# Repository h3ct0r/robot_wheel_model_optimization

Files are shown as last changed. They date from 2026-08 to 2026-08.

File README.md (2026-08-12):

# robot_wheel_model_optimization

Automatic optimisation of the 3D layout of wheels — **rigid (PLA/PETG) and compliant
(TPU), both candidates** — for a real, measured mobile robot: a 426 × 231 × 187 mm, 8.5 kg
four-wheel skid-steer pipe robot on Dynamixel MX-64 servos, carrying 20.6 N per wheel
(`configs/pipebot_detailed.stl`; `configs/robot.yaml` is the spec).

A parametric CAD model generates candidate wheels. Each is characterised by offline FEA,
reduced to a fast lumped-parameter ring model, and evaluated in closed-loop dynamic
simulation across an obstacle-traversal scenario suite. A multi-objective optimiser proposes
the next candidates. Designs are constrained to be FDM-printable, and the pipeline closes to
hardware.

**New here?** Read [`docs/OVERVIEW.md`](docs/OVERVIEW.md) — the project in plain language,
with a glossary of every acronym. No prior knowledge assumed.

**Status:** Phase 0 **closed** (2026-08-11); Phase 1's FEA→ROM pipeline is substantially
built. Current family is the `T7` compliant claw. The headline that matters now is the
**washboard**: a compliant twelve-claw wheel beats the rigid cylinder **4.8–6.9×** on ride
harshness at every wavelength tested, at equal speed. (The spike's old "50 mm vs 20 mm" step
number was superseded twice — it was a banded design on a single-wheel rig.) On the
measured platform the rover's step ladder separates compliant from rigid (claws 1.00 R
against the cylinder's 0.67 R) but not claw counts from each other; within the family,
harshness ranks — see `docs/plan/TODO.md` #30/#33. The ROM's
validity envelope is measured and printed on every run. Open items are numbered in
[`docs/plan/TODO.md`](docs/plan/TODO.md).

## Quick start

```bash
source /opt/homebrew/Caskroom/miniforge/base/etc/profile.d/conda.sh
conda activate conda3.12
python -m unittest discover -s tests -t .          # ~850 tests, ~50 s
python scripts/explore.py --spokes 8 --no-sim      # a design → one HTML page
```

Full setup, and why the first line is needed, is in [Environment](#environment) below.

## Where things are

| Path | Contents |
|---|---|
| [`docs/OVERVIEW.md`](docs/OVERVIEW.md) | **Start here** — plain-language summary and glossary |
| [`docs/run_rover.md`](docs/run_rover.md) | Every `run_rover.py` flag, with figures — the whole robot at an obstacle |
| [`CLAUDE.md`](CLAUDE.md) | Working context — current phase, invariants, conventions |
| [`docs/plan/`](docs/plan/00-index.md) | The project plan, split into loadable sections |
| [`docs/decisions/`](docs/decisions/README.md) | Architecture decision records |
| [`docs/experiments/log.md`](docs/experiments/log.md) | Append-only experiment log |
| [`configs/robot.yaml`](configs/robot.yaml) | The platform spec — sized to the real chassis, not yet frozen |
| [`docs/plan/TODO.md`](docs/plan/TODO.md) | **Open work, numbered** — read before picking something up |
| `src/wheelopt/cad/` | Parametric geometry → STEP + STL + mass properties |
| `src/wheelopt/fea/` | CalculiX driver: STEP → mesh → load cases → stiffness curve |
| `src/wheelopt/rom/` | The segmented ring and its fit. Pure numpy except `mjcf.py` |
| `src/wheelopt/sim/` | MuJoCo scenario runners — the step-climb rig and its signatures |
| `src/wheelopt/report.py` | The self-contained HTML report behind `scripts/explore.py` |
| `scripts/` | Entry points. `explore.py` is the manual playground; `verify_*.py` are the gates |

## The scenario suite

Every design is scored over these scenarios (`docs/plan/08-metrics.md`), each a real
`run_rover.py` run. The frames below are rendered from the simulation itself by
`scripts/render_scenario_gallery.py` — rigid R 60 wheels, the measured platform, the
robot's own shell — so they regenerate with the models they depict.

<table>
<tr>
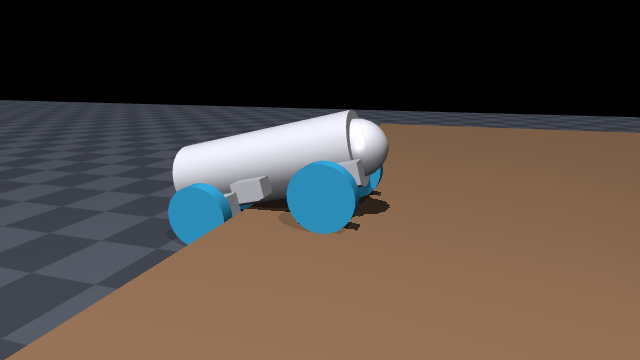
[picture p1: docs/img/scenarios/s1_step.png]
S1 step
<td width="50%"><br/>
<b>S1 — Step.</b> The obstacle ladder, 10–200 mm, swept over friction and approach-angle
seeds. Metric: the step height cleared with P = 0.9. Rigid R 60 clears 0.67 R; the claw
family 1.00 R.</td>
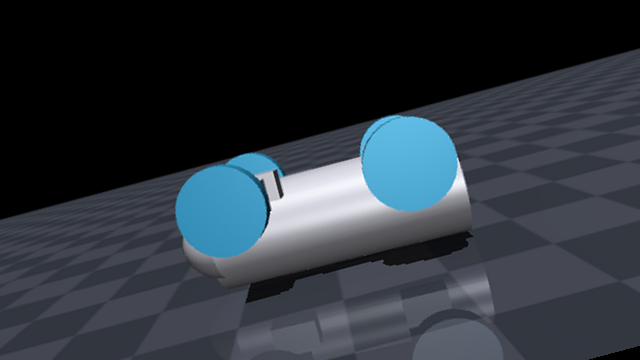
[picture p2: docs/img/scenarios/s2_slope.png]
S2 slope
<td width="50%"><br/>
<b>S2 — Slope.</b> An uphill gradient, implemented by tilting <i>gravity</i> so there is no
ramp-entry transient (the image is rotated by the same angle). Metric: max sustained
gradient. Rigid R 60 holds 10°, backslides at 40° — traction-limited.</td>
</tr>
<tr>
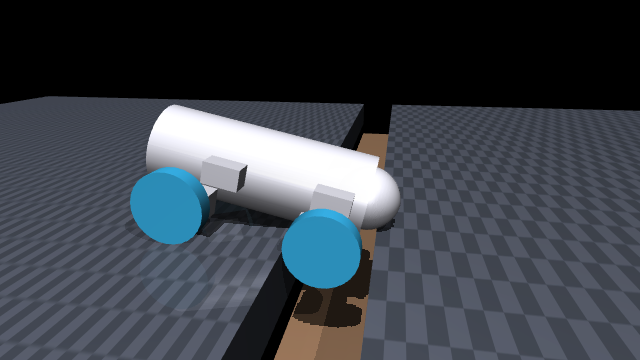
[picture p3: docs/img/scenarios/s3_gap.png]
S3 gap
<td><br/>
<b>S3 — Gap.</b> A 150 mm-deep trench across the ground; a wheel that drops in stays in
(pictured). Metric: max gap crossed with the whole body at ride height on the far side.
R 60 crosses 40 mm and is swallowed by 200.</td>
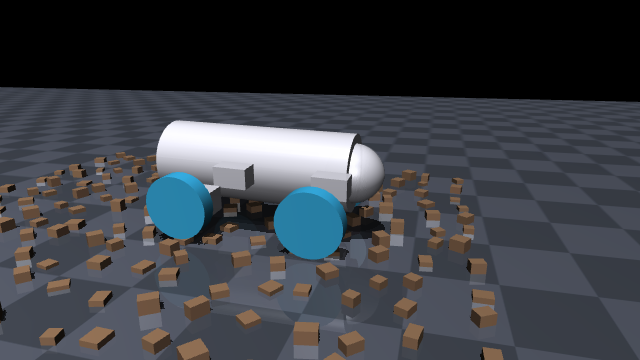
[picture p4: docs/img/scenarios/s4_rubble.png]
S4 rubble
<td><br/>
<b>S4 — Rubble.</b> A procedural rock field where the <i>seed is the terrain</i> —
bit-identical per seed, every rock buried and height-capped, by test. Metric: traverse
success and mean speed over seeds.</td>
</tr>
<tr>
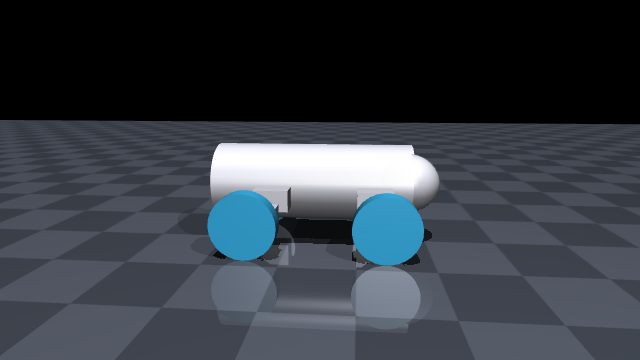
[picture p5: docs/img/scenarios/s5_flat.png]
S5 flat
<td><br/>
<b>S5 — Flat / cost of transport.</b> The anti-soft scenario: <code>E/(m·g·d)</code> on
flat ground, where a rigid cylinder is nearly free (0.01) and excess softness has to pay
for itself. Also the ride-harshness floor (objective 3).</td>
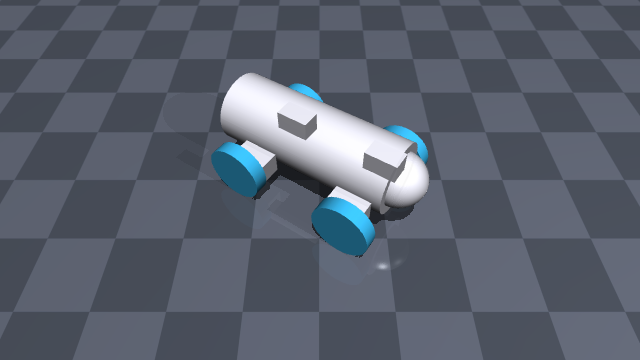
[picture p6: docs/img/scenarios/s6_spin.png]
S6 spin
<td><br/>
<b>S6 — Spin in place</b> (the path-track proxy). Left and right sides driven in
opposition; metric: yaw rate and the scrub energy it costs (6.8 °/s for 45.6 J on rigid
R 60). <i>Quarantined by TODO #38</i> until the lateral-scrub checks land.</td>
</tr>
<tr>
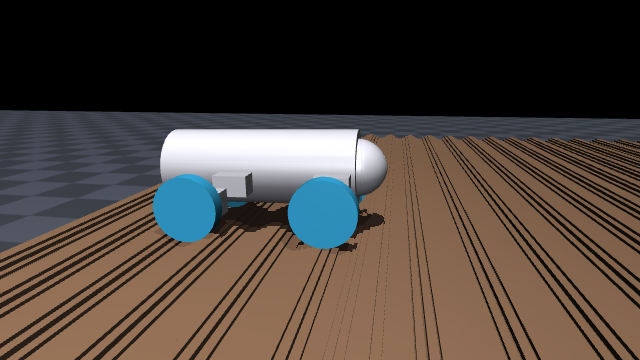
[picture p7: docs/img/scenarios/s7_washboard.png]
S7 washboard
<td><br/>
<b>S7 — Washboard.</b> A sinusoidal corrugation, swept over amplitude × wavelength.
Metric: RMS chassis acceleration — <b>where compliance wins</b>: the claw wheel beats the
rigid cylinder in every cell, 1.7–4.9×, and decouples from the terrain.</td>
<td><b>S8 — Sustained load</b> (no picture yet). Nominal + 2× load over long duration:
sag, buckling margin, fatigue. The anti-collapse scenario. Today it exists as FEA-side
constraints (<code>fea_static_sag</code>, <code>fea_buckling</code>); the duration and
fatigue half wants the TPU coupon data from <code>docs/plan/07-materials.md</code>.</td>
</tr>
</table>

## Environment

One conda environment, `conda3.12` (Python 3.12). Conda rather than a venv for two specific
reasons: **CalculiX has no PyPI distribution** (it is a Fortran binary, invoked as a
subprocess — [ADR-0005](docs/decisions/0005-calculix-for-batch-fea.md)), and **PyChrono has none either** — optional
since [ADR-0008](docs/decisions/0008-hardware-as-ground-truth.md) made printed hardware the ground truth. Everything else
installs from PyPI into the same environment.

### Activating it

```bash
source /opt/homebrew/Caskroom/miniforge/base/etc/profile.d/conda.sh
conda activate conda3.12
```

**The `source` line is not optional on this machine.** Running `conda activate conda3.12` on
its own fails with `Run 'conda init' before 'conda activate'`, because the conda-init block in
`~/.zshrc` is commented out *and* points at `/Users/h3ct0r/miniconda3`, a prefix that no longer
exists. (The `mamba` block just below it points at the same dead prefix, so the `mamba` alias
in that shell is also stale.) The working install is the homebrew miniforge one under
`/opt/homebrew/Caskroom/miniforge/base`.

To make plain `conda activate conda3.12` work permanently, initialise the shell against the
*live* prefix once — this edits `~/.zshrc`, so it is left as your call rather than done for you:

```bash
/opt/homebrew/Caskroom/miniforge/base/bin/conda init zsh
```

Then delete the two dead blocks in `~/.zshrc` that reference `miniconda3`, and open a new
shell.

**Do not use the system `python3`.** Homebrew's 3.14.6 ships a broken `pyexpat` that breaks
`pip` itself.

### Creating it from scratch

```bash
brew install --cask miniforge
conda create -y -n conda3.12 -c conda-forge python=3.12 calculix=2.23
conda activate conda3.12
pip install -e '.[cad,fea,sim,viz,store,dev]'
```

### Checking it

```bash
python -c "import sys; print(sys.executable)"   # .../envs/conda3.12/bin/python
ccx -v                                          # CalculiX Version 2.23
python -m unittest discover -s tests -t .       # 824 tests
```

`ccx -v` prints the version and then **exits 201**. That is normal — it is not an error, and
nothing in the pipeline reads that exit code.

### What needs what

The extras are separate on purpose: a screening-only worker installs none of them, and the
numpy-only layers stay testable on a machine with no CAD kernel and no simulator.

| Extra | Brings | Needed by |
|---|---|---|
| *(none)* | numpy only | screening, centreline geometry, mass properties, the ring maths and its fit |
| `cad` | build123d / OCCT | building solids, STEP and STL export |
| `fea` | gmsh | meshing. **The solver `ccx` is a conda binary, not a pip package** |
| `sim` | mujoco | the ring in dynamics, the step-climb rig, rendering |
| `viz` | matplotlib | `--plot-pdf` and the HTML report |
| `store` | duckdb + pyarrow | the experiment store and the determinism gate |

## Running it

Everything below assumes the environment is active. Times are on this machine; the FEA cache
is content-addressed, so a repeated design is near-instant.

### The playground — start here

One design (or several) through the whole chain into a single self-contained HTML page:
section drawing, load curve, tangent stiffness, contact patch, fitted segment law, step-climb
signatures and an embedded animation.

```bash
python scripts/explore.py --spokes 8 --thickness 6 --no-sim      # ~1 min cold, ~2 s cached
python scripts/explore.py --compare spokes=6,10,14 --no-sim      # shared axes
python scripts/explore.py --rim-thickness 0 --claw-taper 0.6 --spoke-phase -90
```

Output lands in `data/explore/explore.html`. Every panel is labelled with the tier that
produced it and whether that tier **screens or decides**; panels whose numbers are currently
untrustworthy carry a caution banner. Read the banner before quoting the number.

### Individual stages

```bash
# What every geometry parameter does, one figure per parameter, with the screening
# verdict under each design. Seconds, and needs no CAD kernel.
python scripts/plot_geometry.py --contact-sheet

# Screen a design without building geometry. Milliseconds, no OCCT.
python scripts/gen_wheel.py --screen-only --spokes 14 --thickness 6.0

# Build it: STEP + STL + mass properties.
python scripts/gen_wheel.py --radius 85 --spokes 12 --profile curved --out data/wheels

# FEA, mesh and deck only, no solver. The developer loop.
python scripts/run_fea.py --dry-run --tiny --case flat --case step_edge

# FEA on the fast 2-D screening tier. Seconds, not hours.
# (the softened contact penalty this tier once needed by hand is the default since #12)
python scripts/run_fea.py --plane-strain --size-spoke 0.0025 --size-rim 0.003 \
    --size-hub 0.002 --case flat --plot-pdf

# Fit the segmented ring to the FEA curve, and optionally press it in MuJoCo.
python scripts/run_rom.py --tiny --mujoco

# Drive the fitted ring at a step beside a rigid wheel; judge the five signatures.
python scripts/run_step.py --tiny --sweep

# The whole robot — chassis, four driven wheels, its own shell drawn over the
# contact box — at an obstacle, filmed. --chassis-collision primitives swaps the
# calibrated box for the shapes of the simplified model (a physics change).
python scripts/run_rover.py --obstacle-height 80 --radius 85 --render

# Scenario S7: a washboard, where compliance beats rigid on harshness.
python scripts/run_rover.py --obstacle-height 0 --washboard 10 --wavelength 100 --radius 60

# Render the step climb: GIF plus a compliant-vs-rigid contact sheet.
python scripts/render_step.py --tiny
```

`run_rover.py` has the largest flag surface of any entry point here — the obstacle, the
platform, a whole wheel design, the FEA behind it, and the render. Every flag is documented
with figures in **[`docs/run_rover.md`](docs/run_rover.md)**, including which flags are
silently unused in the default rigid-cylinder mode.

### Verification batteries

Run these after touching the layer they cover. They need the real kernels — the unit tests
deliberately cannot catch what these catch.

```bash
python scripts/verify_cad.py            # 48 checks against OCCT
python scripts/verify_fea.py --full     # 30 checks against CalculiX (tens of minutes uncached)
python -m unittest discover -s tests -t .
```

### A caveat worth reading once

The 2-D plane-strain tier is what makes the loop interactive, and it is a **deliberate
fidelity reduction, not an approximation that improves with refinement**. It cannot see
lateral spoke buckling at all. Measured against the 3-D solid at matched settings: force ratio
0.90, stiffness ratio 0.86, patch length 0.95. Use it to screen; let the 3-D tier decide.

## Approach in one paragraph

Full FEM of a compliant wheel inside an optimisation loop is 3–5 orders of magnitude too
slow; rigid-body simulation cannot represent contact-patch growth, load-dependent rolling
radius, or hysteretic loss at all. The approach borrows the automotive tire field's solution:
generate a reduced-order flexible-ring model from FEA, run that in a fast rigid-body engine,
and — after a few hundred FEA runs — surrogate the FEA step away entirely so that design
*search* becomes tractable. Validity is checked by cross-engine rank correlation against
Chrono ANCF FEA tires, and finally against printed hardware.

## Key decisions at a glance

- **MuJoCo** hosts the inner loop. Isaac soft bodies are unusable here — PhysX soft bodies
  don't support static friction. ([ADR-0001](docs/decisions/0001-mujoco-over-isaac-for-inner-loop.md))
- **Reduced-order ring model**, calibrated offline from FEA. FEM never runs in the loop.
  ([ADR-0002](docs/decisions/0002-reduced-order-model-over-fem.md))
- **build123d** for CAD, because FEA needs STEP and multi-material needs region tagging.
  ([ADR-0003](docs/decisions/0003-build123d-over-openscad.md))
- **Printed hardware** as ground truth; Chrono ANCF demoted to an optional cross-check.
  ([ADR-0008](docs/decisions/0008-hardware-as-ground-truth.md), superseding [ADR-0004](docs/decisions/0004-chrono-as-ground-truth.md)'s gating role)
- **Pareto search on CVaR**, no scalarisation, measured termination.
  ([ADR-0006](docs/decisions/0006-multi-objective-not-scalarised.md))

## Licence

TBD.

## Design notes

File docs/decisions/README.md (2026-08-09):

# Architecture decision records

One file per non-obvious decision. **Read the relevant ADR before proposing a change to
simulator choice, modelling fidelity, or the CAD toolchain** — several plausible-sounding
alternatives were evaluated and rejected for specific documented reasons.

| ADR | Decision | Status |
|---|---|---|
| [0001](0001-mujoco-over-isaac-for-inner-loop.md) | MuJoCo hosts the inner loop; Isaac soft bodies rejected (no static friction) | accepted |
| [0002](0002-reduced-order-model-over-fem.md) | Reduced-order ring model calibrated from FEA; **FEM never in the loop** | accepted |
| [0003](0003-build123d-over-openscad.md) | build123d for CAD; STEP required for FEA and material region tagging | accepted |
| [0004](0004-chrono-as-ground-truth.md) | Chrono ANCF as computational ground truth; never in the loop | accepted |
| [0005](0005-calculix-for-batch-fea.md) | CalculiX for batch quasi-static FEA; FEniCSx as escape hatch | accepted |
| [0006](0006-multi-objective-not-scalarised.md) | Pareto search on CVaR; no scalarisation; measured termination | accepted |
| [0007](0007-coacd-for-convex-decomposition.md) | CoACD over V-HACD for collision geometry | accepted |

## Conventions

- Number sequentially. Never renumber.
- **Supersede, don't delete.** When a decision changes, write a new ADR that supersedes the
  old one and mark the old one `superseded by ADR-NNNN`. The reasoning that turned out wrong
  is as valuable as the reasoning that turned out right.
- Keep them short — roughly one page. Context, decision, alternatives *with specific reasons*,
  consequences, revisit-if.
- The **"Revisit if"** section is the most valuable part. It states the observable condition
  that would justify reopening the question, which prevents both premature churn and stubborn
  adherence.
- Use [`0000-template.md`](0000-template.md) as the starting point.

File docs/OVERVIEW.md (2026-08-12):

# Overview — the project in plain language

A one-sitting orientation. No prior knowledge assumed. Every acronym is spelled out the
first time and collected in the [glossary](#glossary) at the end.

The detailed plan lives in [`docs/plan/`](plan/00-index.md); this file is the map, not the
territory.

---

## 1. What we are building, in one paragraph

We are designing **3D-printed wheels — both stiff plastic and squishy TPU, the optimiser
picks** — for a real four-wheeled pipe-inspection robot about the size of a large toolbox:
426 × 231 × 187 mm, 8.5 kg, on four Dynamixel servos, measured off its own 3D model
(`configs/pipebot_detailed.stl`). Each wheel carries about 20.6 N, bolts to the servo's
53 mm horn, and comes out 80–180 mm across.
Instead of guessing a good wheel shape, we let a computer try thousands of shapes, simulate each one driving at obstacles, and pick
the best. The hard part is not the searching. The hard part is **simulating squishiness fast
enough to search at all**. Most of this project is the machinery that makes that possible.

## 2. The problem, and why it is hard

**Rigid wheels are easy to simulate and bad at obstacles.** A hard plastic wheel touches the
ground at essentially one point. Hitting a step, it either has enough torque and radius to
climb, or it stalls.

**Squishy wheels are good at obstacles and hard to simulate.** A soft wheel *wraps around* a
step edge. That does three useful things at once:

1. it grips more, because more rubber is touching the obstacle,
2. it effectively grabs the corner instead of pushing against it,
3. it absorbs shock, so the robot is not shaken apart.

The catch: soft wheels are also slower and less efficient on flat ground, because squishing
and un-squishing wastes energy. **So there is a real trade-off to optimise** — that is the
research question, not a foregone conclusion.

**Why simulating squishiness is hard.** Properly simulating a deforming rubber structure
means finite element analysis (FEA) — chopping the wheel into ~50,000 little chunks and
solving how each one pushes on its neighbours. That takes **minutes per wheel position**. To
optimise, we need to simulate a robot *driving* — thousands of positions per run, thousands
of runs. Doing it directly would be roughly **1,000 to 100,000 times too slow**.

> The naive fix — telling the physics engine "make the contact a bit soft" — does not work.
> That is a numerical smoothing knob, not a model of rubber. It cannot reproduce the contact
> patch growing under load, the wheel wrapping a corner, or energy loss. Mistaking one for
> the other is the single easiest way to get a confident, wrong answer, so the project bans
> it outright (see [invariant 8](#7-the-rules-we-do-not-break)).

## 3. The core idea

Borrowed from the car-tyre industry, which solved this decades ago:

> **Measure the squishiness carefully once. Boil it down to a handful of numbers. Then
> simulate a cheap fake wheel that behaves the same way.**

Concretely, we replace the soft wheel with a **ring of 24–48 rigid blocks connected by
springs**. It is not made of rubber, and it does not deform like rubber internally — but
under load it *pushes back* like the real wheel does, because we tuned the springs to match
the slow accurate simulation. That fake wheel runs fast enough to drive around.

The technical name for "cheap stand-in tuned to match an expensive model" is a
**reduced-order model (ROM)**. It is the heart of the project.

```mermaid
flowchart LR
    A["<b>1. CAD</b><br/>describe a wheel<br/>with ~10 numbers"]
    B["<b>2. FEA</b><br/>squash it slowly<br/>and accurately<br/><i>minutes</i>"]
    C["<b>3. ROM</b><br/>fit a spring-ring<br/>to match<br/><i>seconds</i>"]
    D["<b>4. SIM</b><br/>drive at obstacles<br/>thousands of times<br/><i>milliseconds</i>"]
    E["<b>5. OPTIMISER</b><br/>propose better<br/>wheels"]
    A --> B --> C --> D --> E
    E -.->|next candidate| A
```

**The key structural rule: step 2 never runs inside the loop.** FEA happens once per design,
offline, and the result is cached. The loop only ever runs the cheap version. Later, we skip
even that — after a few hundred designs we train a predictor that guesses the spring values
straight from the shape, so most designs skip FEA entirely.

## 4. The pipeline, stage by stage

| # | Stage | Input | Output | Software | Speed |
|---|---|---|---|---|---|
| 1 | **CAD** — build the shape | ~10 numbers (radius, spoke count, thickness…) | 3-D solid + weight | **build123d** — the Python library we write shapes in. **OCCT** (via **OCP**) — the geometry kernel underneath it, which does the actual solid modelling and writes the STEP file. **NumPy** — spoke maths, screening and weight, all of which run *without* the kernel. **matplotlib** — optional, draws the PDF report | seconds |
| 2 | **FEA** — measure stiffness | the 3-D solid, or a slice through it | how hard it pushes back | **gmsh** — chops the wheel into ~50,000 tetrahedra, or the flat cross-section into ~2,600 triangles. **CalculiX** (`ccx` 2.23) — the solver; a standalone program we launch and exchange text files with, not a Python library. **NumPy** — reads the solver's output back and extracts the curve | ~20 s for a slice, ~20 h for the full solid |
| 3 | **ROM** — fit the stand-in | the stiffness curve | spring settings | **NumPy** / **SciPy** — the curve fitting itself. **MuJoCo** — the ring model is built and exercised here to check the fit is real. Later, **BoTorch** / **GPyTorch** — a predictor that guesses spring settings straight from the shape, skipping FEA entirely | seconds |
| 4 | **SIM** — drive it | the spring-ring wheel | did it climb? how fast? how much energy? | **MuJoCo** — the fast physics engine that runs the scenarios. **CoACD** + **trimesh** — cut the shape into simple convex pieces the engine can collide quickly. **PyChrono** — a slower, much more accurate independent simulator, used only to check the cheap model, never inside the loop | milliseconds |
| 5 | **OPTIMISER** — choose next | all scores so far | the next shapes to try | **Ax** / **BoTorch** — the Bayesian optimiser. **CMA-ES** or **NSGA-II** — final local polish, which evolution strategies do better than Bayesian methods. **Hydra** — configuration, so no number is buried in code. **DuckDB** + **Parquet** — stores every run, one row per design × scenario × seed | seconds |

Installed and running today: everything in stages 1 and 2, plus NumPy throughout. The rest is
the intended stack, chosen in the decision records (§8) but not yet built — see the road map
in §6. All of it is free and open-source, and all of it runs on one laptop.

Two practical notes. **CalculiX and PyChrono are not normal Python packages**: `ccx` is a
compiled program that we run as a separate process, and PyChrono has no PyPI release at all.
That is the entire reason the project uses a conda environment rather than a plain
`virtualenv`. And **the heavy pieces are optional** — a machine that only screens designs for
printability needs NumPy and nothing else, which is why the install is split into
`[cad]`, `[fea]` and `[viz]` extras.

### Stage 1 — CAD (Computer-Aided Design)

A program writes the wheel, rather than a human drawing it. Give it a handful of numbers —
outer radius, width, number of spokes, spoke thickness, how curved the spokes are — and it
produces a real 3-D solid.

It also **screens the design first**, in milliseconds: are the spokes so close together the
printer nozzle cannot fit between them? Is it too big for the robot? A bad design is rejected
before any expensive work happens.

*Status: done and verified.*

### Stage 2 — FEA (Finite Element Analysis)

Take the solid, chop it into ~50,000 tetrahedra, and press it against an obstacle in small
steps, solving the whole structure each time. We do this twice:

- **against a flat plate** — the reference measurement,
- **against a step edge** — the case that actually decides obstacle climbing, and the one the
  published tyre literature tends to skip.

Out comes the **stiffness curve** `k_r(δ)`: how much force it takes to squash the wheel by a
given amount. Plus the contact patch size, how much the wheel's effective radius shrinks
under load, and whether the spokes buckle.

*Status: done and verified — 20/20 checks pass.*

### Stage 3 — ROM (Reduced-Order Model)

Fit the ring-of-blocks-and-springs so its force-versus-squash curve matches what FEA
measured. Then check honestly how close the match is, and report the error.

*Status: next up.*

### Stage 4 — SIM (dynamic simulation)

Drive the robot at obstacles in MuJoCo, a fast physics engine. Eight scenarios (S1–S8):
steps, slopes, gaps, rubble, a flat sprint, path following, washboard ripples, sustained
load. Each design is scored on obstacle capability, energy use, speed and ride quality.

Every design is run many times over **different random terrains and different plausible
rubber properties**, because we do not precisely know the material — and a design that only
works for one exact rubber recipe is useless in practice.

*Status: not started.*

### Stage 5 — OPTIMISER

Propose the next batch of shapes to try, using Bayesian optimisation — a method that builds a
running guess of "which regions of the design space look promising" and samples there.

Crucially it keeps the objectives **separate** rather than mashing them into one score. There
is no single best wheel; there is a *set* of best trade-offs (a **Pareto front**) — this one
climbs better, that one is more efficient. Collapsing that into one number destroys the
actual result.

*Status: not started.*

## 5. Where the project is right now

**Phase 0 (foundations) closed 2026-08-11; Phase 1's FEA→ROM pipeline is substantially
built**, well ahead of the original [one-week spike](plan/16-first-week.md) whose steps the
table below tracks — all six answered yes. The ground truth is now printed hardware
(ADR-0008), and the next gate is a bench press test of a printed wheel.

| Step | What | Status |
|---|---|---|
| 1 | Freeze the robot specification | measured robot adopted 2026-08-11; frozen once CoM/inertia arrive |
| 2 | CAD: shape → 3-D solid | **done**, 60/60 checks |
| 3 | FEA: solid → stiffness curve | **done**, 30/30 checks, plus a fast 2-D screening tier |
| 4 | ROM: fit the spring-ring | **done** — and for claw wheels the law is *measured*, not fitted |
| 5 | Drive it at a step edge vs a rigid wheel | **done** — 5/5 signatures; the whole 4-wheel robot runs too |
| 6 | Look hard at the result, decide whether to continue | **yes** — compliance beats rigid on the washboard and on the rover's step ladder |

**What we already know works.** A test wheel (60 mm radius, 6 spokes, TPU) pressed into an
obstacle behaves correctly: it gets stiffer the more you squash it, its contact patch
grows, its effective radius shrinks, and — the important one — **against a step edge the
contact is smaller and the pressure higher than against a flat plate**. That is the
envelopment signature. It is the mechanism that lets a soft wheel climb, and it showed up in
the numbers without being put there.

**The big open question**, and the reason for the spike: does the cheap spring-ring model
actually reproduce the real behaviour well enough to optimise against? If not, the plan is to
fall back to a simpler wheel family (soft tread on a rigid hub) and narrow the claims. Better
to learn that in week 14 than week 30.

## 6. The road map

| Phase | Weeks | What happens | Gate to pass |
|---|---|---|---|
| **0 Foundations** | 1–4 | Robot spec, repo, rigid wheel rolling end-to-end | Same design → same score, two machines, two days apart |
| **1 FEA + ROM** | 5–14 | The critical path. Build and validate the stand-in model | ROM within 10% of FEA stiffness; ranking agreement ρ > 0.8 |
| **2 Optimiser** | 15–24 | Full scenario suite, ≥ 300 designs/day, train the shape → springs predictor | Beats random search, with confidence intervals |
| **3 Main campaign** | 25–36 | 2,500–3,500 designs across all wheel families; validity audits | Cross-engine agreement ρ > 0.7 |
| **4 Hardware** | 37–50 | Print 8 wheels, build a test rig, measure reality | Sim-to-real correlation reported honestly, whatever it is |
| **5 Write-up** | 51–60 | Release the benchmark; papers | — |

A **gate** is a go/no-go checkpoint. Failing one means stopping and rethinking, not pressing
on. Phase 1's gate is the one that matters most: *if the cheap model cannot reproduce the
expensive one, the whole approach needs rethinking.*

## 7. The rules we do not break

These are in [`CLAUDE.md`](../CLAUDE.md) as "invariants". In plain terms:

1. **Never run the slow, accurate simulation inside the search loop.** It is offline and
   cached, always.
2. **Always compute weight and stiffness from the actual shape and material.** Never hard-code
   them, never hold them fixed between designs. A wheel whose stiffness silently never changes
   would produce beautiful, meaningless results.
3. **Rejecting a bad design must be cheap** — milliseconds, not a six-minute simulation.
4. **Nothing crashes the campaign.** A failed simulation returns "this failed, here is why",
   never an error that stops everything. Running thousands of nonlinear simulations
   unattended, some *will* fail; that is normal, and it gets logged as a health metric.
5. **Change the method, invalidate the old results.** Every cached result is tagged with the
   version of the code that produced it, so nothing stale is ever silently reused.
6. **Keep the objectives separate.** No single blended score.
7. **Score every design across many random terrains and material guesses**, and judge it by
   its *bad* days, not its average day (a measure called CVaR). Robustness is a requirement,
   not a refinement.
8. **The physics engine's "soft contact" setting is not squishiness.** Never use it as a
   stand-in for rubber.

## 8. Key decisions, and why

Recorded as ADRs — Architecture Decision Records, one file per decision, in
[`docs/decisions/`](decisions/README.md). Each records what was chosen, what was rejected,
and *why*, so nobody re-litigates it from memory.

| # | Decision | Short reason |
|---|---|---|
| 0001 | MuJoCo for the fast inner loop | Fast and reliable. NVIDIA's soft-body engine was rejected because it has no static friction — meaning no correct grip, which breaks the whole point |
| 0002 | Stand-in model instead of real FEM in the loop | Real FEM is 1,000–100,000× too slow |
| 0003 | build123d for CAD, exporting STEP | FEA needs true curved surfaces, not a triangle mesh |
| 0004 | Chrono as "ground truth" | An independent, much more accurate simulator to check our cheap model against — never used in the loop |
| 0005 | CalculiX for the FEA | Free, scriptable, batch-friendly, boring in the good way |
| 0006 | Keep objectives separate (Pareto) | Blending them into one number destroys the actual finding |
| 0007 | CoACD for collision shapes | Better shape approximation than the older standard |

## 9. Two honest limitations

Stated up front, because they shape what the project can claim:

- **We do not have lab equipment to measure the rubber properly.** We use published values
  and cheap DIY tests. So we cannot make precise absolute predictions — we can rank designs.
  The project turns this into a research question: *how much does not knowing the material
  cost you, and can you optimise in a way that is robust to not knowing?*
- **Energy loss in the rubber is not modelled from first principles.** The material model we
  can afford is "springy but lossless", so the FEA cannot produce a hysteresis (energy-loss)
  number. That is a real gap, and it is written down rather than filled with a plausible
  guess.

## 10. Running things

Everything assumes the project environment is active: `conda activate conda3.12`.

```bash
# Fast checks — no heavy dependencies, about a second.
python -m unittest discover -s tests -t .

# Is this design even buildable? Milliseconds, no CAD kernel.
python scripts/gen_wheel.py --screen-only --spokes 20 --thickness 2.4

# Build a wheel: 3-D file + weight + a PDF drawing.
python scripts/gen_wheel.py --radius 70 --spokes 16 --plot-pdf

# FEA without the solver — builds the mesh and input file only.
python scripts/run_fea.py --dry-run --tiny --case flat --case step_edge

# The real thing: squash the wheel, plot the results.
python scripts/run_fea.py --tiny --case flat --case step_edge --plot-pdf

# Full verification batteries.
python scripts/verify_cad.py
python scripts/verify_fea.py --full
```

---

## Glossary

### The essentials

| Term | Meaning |
|---|---|
| **Compliant** | Squishy. Deforms usefully under load. The opposite of rigid |
| **TPU** | Thermoplastic Polyurethane — flexible 3-D printing filament. The rubber-like stuff |
| **FDM** | Fused Deposition Modelling — ordinary filament 3-D printing |
| **FEA / FEM** | Finite Element Analysis / Method — chop an object into small chunks and solve how it deforms. Accurate, slow |
| **ROM** | Reduced-Order Model — a cheap stand-in tuned to behave like an expensive model |
| **Contact patch** | The area actually touching the ground. Bigger = more grip |
| **Envelopment** | A soft wheel wrapping around an obstacle instead of bumping into it |
| **Buckling** | A slender part suddenly collapsing sideways instead of squashing evenly |
| **Hysteresis** | Energy lost as heat when a material is squashed and released |
| **Pareto front** | The set of best trade-offs, when no single design wins at everything |
| **CVaR** | Conditional Value at Risk — the average of the *worst* outcomes. Judging a design by its bad days |

### File formats and tools

| Term | Meaning |
|---|---|
| **CAD** | Computer-Aided Design |
| **STEP** | Exact 3-D format with true curved surfaces. Our source of truth |
| **STL** | Triangle-mesh 3-D format. Approximate, derived, never authoritative |
| **BREP** | Boundary Representation — how STEP describes shapes exactly |
| **OCCT / OCP** | Open CASCADE Technology — the geometry engine underneath build123d |
| **build123d** | The Python library we write CAD in |
| **gmsh** | Chops a solid into elements for FEA |
| **CalculiX (`ccx`)** | The FEA solver. A standalone program we call and read files from |
| **MuJoCo** | The fast physics engine for the inner loop |
| **Chrono / PyChrono** | A much slower, much more accurate simulator, used as a reference |
| **NumPy / SciPy** | The standard Python numerical libraries. Arrays, and curve fitting |
| **matplotlib** | Draws the PDF reports |
| **CoACD / trimesh** | Cut a shape into simple convex pieces so collisions are fast to compute |
| **Ax / BoTorch / GPyTorch** | Meta's Bayesian-optimisation stack. Ax runs the experiment, BoTorch and GPyTorch do the maths underneath |
| **CMA-ES / NSGA-II** | Evolutionary search methods. Better than Bayesian optimisation at the final polish, worse at the broad hunt |
| **Hydra** | Configuration system, so settings live in files rather than buried in code |
| **DuckDB / Parquet** | A database and a file format for storing results. Fast for "give me every run where…" questions |
| **conda / conda-forge** | Package manager and its community repository. Used here because two of our tools are not installable any other way |
| **ADR** | Architecture Decision Record |

### Things you will see in the code

| Term | Meaning |
|---|---|
| **`k_r(δ)`** | Radial stiffness — how much force to squash the wheel by distance δ. The main FEA output |
| **Load case** | One specific test: "press against a flat plate", "press against a step edge" |
| **Mooney-Rivlin** | A mathematical description of how rubber stiffens as you stretch it |
| **C3D10** | A curved 10-cornered tetrahedral element — the chunk shape our FEA uses |
| **DOF** | Degrees of Freedom — how many unknowns the solver handles. ~50,000 here |
| **Jacobian** | A measure of whether an element is a sane shape or folded inside-out |
| **`T0`…`T6`** | Wheel families: `T0` rigid cylinder (baseline), **`T3` compliant spoke (our main target)**, `T4` all-TPU, `T5` spokes + lugs, `T6` soft tread on rigid hub (fallback) |
| **`S1`…`S8`** | Test scenarios: step, slope, gap, rubble, flat sprint, path tracking, washboard, sustained load |
| **`RQ1`…`RQ4`** | The four research questions — design trade-offs, method, validity, robustness |
| **Invariant** | A rule that must never be broken, listed in `CLAUDE.md` |
| **Gate** | A go/no-go checkpoint at the end of a phase |
| **NPT** | Non-Pneumatic Tire — airless tyres. The closest existing literature |
| **Spearman ρ** | A 0–1 score for "do two rankings agree?" Used to check simulation against reality |

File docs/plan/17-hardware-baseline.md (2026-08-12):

# 17 — Freezing the platform, and the hardware ground-truth protocol

Two jobs in one file, because they share equipment and an afternoon: **(A)** measure the real
robot so `configs/robot.yaml` can set `meta.frozen: true`, and **(B)** the bench protocol
ADR-0008 promotes to ground truth. Everything downstream carries a "these are estimates"
caveat until (A) is done, and the ROM's multi-claw regime has no calibration path until (B).

## A. Freezing `robot.yaml` — every field, how to get it, what it replaces

**Status 2026-08-11: the measurements arrived, and they changed the robot.** Received: the
motor (4x Dynamixel MX-64AT at 12 V — 6.0 N·m stall, 63 rpm no-load, at the output), 8.5 kg
all-up, 3 cm clearance, and the 3D model (`configs/pipebot_detailed.stl`, at the time named `robot_piperobot.stl`). Mining the STL:
**wheelbase 250 mm, track 157 mm (not the assumed 350), overall 426 x 231 x 187, existing
wheels r ~22.5 mm** — a pipe robot with a circular ~187 mm shell, not the assumed
400x300x200 box. The model's own clearance (34 mm) cross-checks the hand measurement. The
searched wheel range (R 60-100) collides with the real machine; adoption of the measured
geometry is pending the open questions below.

**Open questions the STL cannot answer** (they gate the design-space re-derivation):
1. **Must the robot keep fitting a pipe, and what bore(s)?** The circular shell says
   pipe-fit; a larger wheel lifts the whole body and changes that fit. This sets the wheel
   radius ceiling, which no geometry measurement can.
2. **What rotates at r 26.5 mm from the axles** — servo horn (rotates, caps nothing) or a
   fixed bracket (caps the wheel at ~26 mm)? One photo of a wheel answers it.
3. **How much axial room is there for a wider wheel** outboard/inboard of the current one?
4. The 8.5 kg: with or without the current wheels and battery? (Now minor — the existing
   wheels are tiny — but it settles `nominal_wheel_load`.)

Ordered by leverage: the first three touch every number in the project.
**The table predates the 2026-08-11 arrival and is kept as the method reference** — its
"current" column shows the old estimates the measurements replaced. Still genuinely open:
`com_offset`, `inertia` (both want the 3D model with component masses assigned), and the
per-corner masses.

| Field | Current (estimate) | How to measure | Effort |
|---|---|---|---|
| `chassis.mass` | 8.8 kg | Bathroom/kitchen scale, robot ready-to-run **with battery, without wheels**. Weigh wheels separately | 5 min |
| `motor.stall_torque` (at output) | 4.0 N·m | Preferred: **datasheet** from the motor brand + gear ratio (see below). Cross-check: lever arm clamped to one axle pressing on a kitchen scale at a known radius, battery at working charge, brief stall — `τ = m·g·r`. Keep stalls under ~2 s | 30 min |
| `motor.no_load_speed` | 14.0 rad/s | Datasheet, cross-checked by video: tape flag on a wheel, phone slow-mo (240 fps), count frames per revolution at full throttle off the ground | 15 min |
| `chassis.com_offset` | (0, 0, 0) | Balance method: find the tip line by tilting the robot on a straightedge along each axis; or read it from the **3D model** if component masses (battery!) are placed. The z-offset moves both tip-over angles directly — objective 5 depends on it | 30 min |
| `chassis.inertia` | uniform-box formula | From the **3D model** with real component masses assigned (any CAD package reports it). The box formula over-estimates for a robot whose mass concentrates low and central — which flatters nothing but is wrong | via 3D model |
| `wheelbase`, `track` | 260 / 350 mm | Tape measure axle-to-axle, or the 3D model. Trust the model only if the built robot matches it | 5 min |
| `ground_clearance` | 70 mm | Measure under the chassis at ride height with current wheels | 2 min |
| `wheel_envelope.max_radius` | 100 mm (**derived from a dead printer**) | The chassis wheel well: from the 3D model, the largest radius that clears body, fasteners and neighbouring wheel at full articulation, minus 5 mm | via 3D model |
| `shaft` interface | 8 mm D-shaft | Calipers on the actual shaft + flat depth | 5 min |
| `nominal_wheel_load` | 24.5 N | Derived: `(chassis + 4 wheels) · g / 4` once mass is real. Optionally verified per-corner with the scale under one wheel | derived |

**What Claude needs from you to do the desk half:**
1. **The motor brand and model string** (and gearbox ratio if separate) — the datasheet gives
   stall torque, no-load speed, stall current, and the torque constant; the YAML wants
   output-shaft values, so the ratio and its efficiency matter.
2. **The 3D model** (STEP preferred; STL works for measurement) — for the wheel well radius,
   CoM and inertia with masses assigned, and wheelbase/track as-designed.
3. **Three numbers you measure**: all-up mass with battery, per-corner mass on one front and
   one rear wheel (CoM x-offset falls out of the difference), and ground clearance.

With those, the YAML gets filled, the cross-checks in `platform.consistency_warnings` get
re-run, `meta.frozen` flips to true — and `LoadCase.nominal_load_n` plus every cache key
downstream is re-derived once, deliberately, in a single commit.

## B. The bench press test — the ground-truth instrument (ADR-0008)

**What it measures:** the quasi-static whole-wheel load curve `F(δ)` of a printed wheel —
the exact quantity the FEA sweeps produce and the ROM is built from. One rig, three uses:
validate the FEA→print gap, calibrate the ring's multi-claw regime (#31), and provide the
material-realisation spread invariant 7 wants sampled.

**The rig, deliberately primitive:**
- A printed wheel on a stub shaft (print the shaft adapter too), pressed tip-down onto a
  **kitchen scale** (0.1 g class, ≥5 kg range) resting on a hard flat surface.
- Displacement by any of: a drill press or lab stand with a depth stop; a printed screw jack
  (M8 threaded rod = 1.25 mm/turn, quarter-turns give 0.31 mm steps); or shims. Read
  displacement with calipers between two reference faces.
- Protocol: load in ~1 mm steps to 20 mm and back, 10 s settle per point (TPU creeps — the
  settle time is part of the measurement, record it), read force at each. Repeat the sweep
  twice per wheel; print each design **twice** and treat print-to-print spread as material
  realisation data, not error.
- Phase matters on a bandless wheel: press once tip-down and once gap-down
  (`phase_for_tip_contact` says which is which); the difference is the polygon effect the
  harshness metric rides on, measured for free.

**Acceptance uses:** single-claw regime — ROM within 10% of the printed curve (the new
Phase 1 gate); multi-claw regime — the printed curve **is** the calibration target the ring
is fitted to above second-claw engagement. Log every curve to the store like any run.

**Later, same rig family (not needed to start):** spin-in-place on a known surface for the
#38 scrub/friction ground truth (command a slow yaw, film it, compare yaw rate against the
MuJoCo prediction); a step-edge press (a board clamped under half the scale) for the
`RADIAL_STEP_EDGE` case.

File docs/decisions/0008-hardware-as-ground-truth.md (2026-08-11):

# ADR-0008 — Hardware as ground truth; Chrono demoted to optional

**Status:** accepted
**Date:** 2026-08-11
**Supersedes:** the *gating role* of ADR-0004. Chrono remains the documented option for a
sim-to-sim cross-check; it no longer blocks anything.

## Context

ADR-0004 made Chrono ANCF the computational ground truth: the Phase 1 gate was "ROM
reproduces Chrono dynamic response ranking with ρ > 0.8 on 10 designs", and the plan named
the ROM-vs-Chrono question the project's blocking unknown. That decision was made when the
robot was a paper specification. Two things have changed:

1. **The robot physically exists**, with a printer beside it. Printing a candidate wheel is
   an overnight job costing tens of grams of TPU; pressing it against a scale is an
   afternoon. The thing Chrono was standing in for — reality — is available at less cost
   than Chrono itself.
2. **The ROM's failure modes turned out to be contact-shaped, not dynamics-shaped.** The
   measured gaps (#31: flank bedding, +75%/−46% element straddle above second-claw
   engagement; the law extrapolating past its swept range) are quasi-static contact
   phenomena a bench press test measures *directly*. A Chrono ANCF tire would model them
   with its own discretisation choices — a second opinion, not a measurement.

Standing up PyChrono (conda-only, its own OCCT collision risk noted in the environment plan)
plus an ANCF tire rig calibrated well enough to arbitrate was weeks of the critical path,
spent building a referee we no longer need.

## Decision

**The validation tier is printed hardware.** The Phase 1 gate becomes:

> The ROM reproduces the **measured quasi-static load curve of a printed wheel** within 10%
> over the single-claw regime, and its multi-claw regime is **calibrated against** (not
> predicted ahead of) the same measurement, on at least 3 printed designs spanning the claw
> family.

Dynamic transfer (the step climb, the washboard ranking) is validated on the robot itself in
Phase 4 as already planned; the bench press test is the new intermediate tier. The DIY
characterisation protocol in `07-materials.md` is promoted from "materials week" to the
validation instrument.

**Chrono is optional.** ADR-0004's engine analysis stands; anyone wanting a sim-to-sim
cross-check (for a publication, or if hardware and simulation disagree and a third opinion
would localise the fault) follows it. Nothing waits on it, and PyChrono is not installed
until someone does.

## Consequences

- The "blocking unknown" (CLAUDE.md) is restated: it is now whether the FEA-calibrated ROM
  reproduces a **printed wheel's** measured behaviour — which also collapses two risks into
  one, since the FEA→print gap (infill, anisotropy, the Gibson-Ashby knock-down) was going
  to need this measurement anyway.
- #31's multi-claw regime gets a calibration path that does not require solving the
  flank-bedding element analytically: measure the printed wheel's whole-wheel curve past
  second-claw engagement and fit the ring's multi-claw response to it, with the analytic
  element retained for the single-claw regime where it is exact.
- The Spearman ρ > 0.7 cross-engine check of Phase 3 becomes a hardware rank-correlation
  check on the printed designs.
- Cost: a bench press rig (kitchen scale, calipers or a printed depth gauge, a clamp) and
  print time. Risk: hardware measurements carry their own noise — mitigated by the protocol
  measuring each design at least twice and treating disagreement between prints as data
  (material realisation spread, which invariant 7 wants sampled anyway).

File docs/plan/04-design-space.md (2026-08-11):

# 04 — Design space

## Topology families

| ID | Family | Material | Notes |
|----|---|---|---|
| `T0` | Smooth rigid cylinder | PLA/PETG | Rigid baseline — needed for the comparison to mean anything |
| `T1` | Grousered rigid | PLA/PETG | Rigid baseline with lugs |
| `T2` | Lobed / star rigid | PLA/PETG | Rigid, discontinuous contact |
| **`T3`** | **Compliant spoke** | **TPU spokes, rigid or TPU hub** | Curved/S-shaped/honeycomb/chevron spokes + thin rim. The NPT archetype |
| **`T4`** | **Monolithic TPU** | **TPU throughout** | Stiffness tuned by infill density/pattern and wall count |
| **`T5`** | **Compliant spoke + lugs** | **TPU** | Conformity plus positive engagement — likely the actual winner for obstacles |
| **`T7`** | **Compliant claw (linear)** | **TPU throughout** | Tapered free-tip fingers from the hub, no band. `T3b` with a taper. **The direction from 2026-08-08** |
| **`T7L`** | **Compliant claw (L)** | **TPU throughout** | `T7` with a tangential **foot** at the tip: a radial leg, a filleted right angle, and a pad lying along the running surface. `tip_hook_mm != 0`. Added 2026-08-11 |
| `T8` | Linkage claw | TPU + pins | Claws driven by a motion-reversing linkage. PaTS-Wheel's own category. Later |
| `T9` | Pivot claw | TPU + pins | Claws hinged at the hub rim. The commonest passive prior art. Later |
| `T6` | Soft tread on rigid hub | PLA hub + TPU tyre | Cheap-to-model comparator; localised deformation only. **Fallback family if the ROM gate fails** |

Start with `T0` and `T3` in Phase 1 — one rigid anchor, one compliant target. Add the rest
progressively.

## Direction, 2026-08-08: bandless claws

**Every future design is bandless.** The shear band is retained in the code and in `T3` as the
thing already measured against, not as a candidate. **Formalised 2026-08-11: the banded-`T3`
machinery is DORMANT** — the coupled ring solver, the hoop/bending band stiffnesses and the
whole-wheel deconvolution fits stay in the tree with their tests as the record of what was
measured, but they are a frozen surface: no new work targets them, their known debts (#32's
default-interval re-fit) are moot until revival, and reviving them is a decision to record
here, not a drive-by. The claw path (`--law claw`) never touches them. What replaces it is `T7`, the compliant
claw: tapered fingers cantilevered off the hub with free tips that are themselves the running
surface.

The naming comes from Table I of the PaTS-Wheel letter (`docs/papers`), a taxonomy of
**existing transformable wheels** — Linear Claw, Linkage Claw, Pivot Claw, Passive Pad Deform.
Two things about that table are easy to get wrong and worth writing down:

- **PaTS-Wheel is not in it.** The paper places its own design *between* Linkage Claw and
  Passive Pad Deform, using pad deformation to actuate the claw. The three rows are prior art
  the authors contrast themselves against.
- **The table's Linear Claw is a rigid mechanism** — bars sliding radially through the hub,
  typically fired by a gear train when the wheel stalls. `T7` borrows its *shape*, not its
  mechanism: the compliance is the printed TPU finger bending, which keeps the design inside
  this project's premise and inside the existing FEA → ROM pipeline.

### What the taper buys, and what it breaks

A bandless spoke is a cantilever with a free tip, so the bending moment is largest at the root
and zero at the tip. A uniform section is over-thick everywhere but the root: it wastes mass
and stiffens the tip precisely where conformity is wanted. `claw_taper_ratio` narrows the
outline linearly in **arc length** from root to tip; 1.0 reproduces the uniform strut exactly.

| Parameter | Range | Notes |
|---|---|---|
| `claw_taper_ratio` | 0.25–1.0 | Tip thickness as a fraction of root. 1.0 = uniform strut. Below 0.25 a tapered cantilever stops behaving like a beam and starts behaving like a hinge — a different model, not a thinner one |

It also adds a **second thickness**, and every check has to read the right one. `7 mm` of root
at `0.15` taper is a 1.05 mm tip: unprintable, while `spoke_thickness_mm` still looks
comfortable. `WheelParams.tip_thickness_mm` exists for this, `spoke_min_wall` and the discrete
contact warning now read it, and both are covered by tests. The **slenderness proxy still reads
the root and is knowingly wrong for a taper** — it understates slenderness and errs toward
accepting a claw that buckles. Picking the right effective section for a tapered cantilever is
buckling physics, not a pre-filter tweak; it is flagged in the code and left to FEA.

### `T7L` — the L claw: a foot on the tip

Added 2026-08-11. `tip_hook_mm` bends the last part of the claw through a right angle so it
lies along the running surface: a radial **leg**, a filleted **bend**, and a tangential
**foot**. Zero — the default — is `T7` unchanged, and a zero-length foot is the continuous
limit of a shortening one, so this is a parameter rather than a topology switch (unlike
`rim_thickness_mm`, whose zero really is one).

| Parameter | Range | Notes |
|---|---|---|
| `tip_hook_mm` | −40 to +40 | Arc length of the foot along the running surface. **Signed**: which way the foot points. 0 is the plain radial claw |

**What it is for.** A radial claw touches at a point, so a bandless wheel is a polygon and its
axle drops `R(1 − cos π/n)` once per tip — measured as ride harshness on 2026-08-10, where a
3-claw wheel reads 22.6 m/s² RMS against a 12-claw wheel's 5.0. A foot spreads the contact over
an arc `β = |tip_hook_mm| / R`, so the axle only falls across what is left between two feet and
the closed form becomes `R(1 − cos(π/n − β/2))`. On R 60 with twelve claws a 12 mm foot takes
the drop from **2.04 mm to 0.78 mm**, and `WheelParams.polygon_drop_mm` reads the field.

**Signed, and the sign is a real design variable.** A foot that trails the leg is dragged onto
the ground and folds closed under drive torque; one that leads it is levered open. Nothing in
this project measures that difference yet, which is why both are expressible and neither is a
default. Note that the mirror image of a claw flips **both** the foot and the curvature — the
CAD battery pins this, because flipping the foot alone on a bowed leg gives a C against an S
and the two differ in volume by 2.3e-5, which is exactly the size that gets waved through as
tolerance.

**The bend radius is load-bearing, not cosmetic.** The outline is the centreline offset by half
the local thickness, and offsetting a corner of centreline radius `ρ` makes the inside face a
circle of radius `ρ − h`: at `ρ = h` it collapses to a point and below it the polygon turns
inside out. OCCT may refuse such a face — or accept it into a solid with a reversed patch whose
volume is still plausible, which is the failure mode this project keeps finding. So
`hook_bend_radius_mm` is `0.75 t_tip` against a half-thickness of `0.5 t_tip`, and
`verify_cad.py` §11 checks the outline for self-intersection **independently of the kernel**.

**The foot follows the circle, not a chord.** Built in polar rather than in the spoke's local
Cartesian frame: a 20 mm straight foot on a 60 mm wheel stands 3.2 mm proud of the running
surface, so it would pierce it and the outline clip would then eat it from outside until, on a
tapered tip, the outline crossed itself.

**What is done and what is not.** CAD, screening, the mid-plane figure and the 2-D FEA tier all
handle it — everything reads `spoke_outline`, so it arrived downstream for free, and a 12 mm
foot on the R 60 twelve-claw design meshes and solves. **The ring ROM does not.** Its segments
carry load at a point along their own radius, which is precisely what a foot is not; this is
`TODO.md` #31 — the flank-contact gap — arriving by design rather than by accident, and #35
tracks what it means for `T7L`.

### `n_spokes` bottoms out at 3, and the interesting limit is not the bound

**Closed twice, in opposite directions, and both are worth keeping straight.**

The original gap read: the Linear Claw figure has four spokes and the bound of 6 rejected it,
so the bound needed re-deriving from the claw load case. **`TODO.md` #19 did that measurement
and the answer was the other way round** — a *passive* claw wheel wants **more** tips, not
fewer. Below about twelve it unloads a claw completely once per pitch, whatever the claw's
stiffness, and the letter's four-claw row is only reachable because those claws are gear-driven
rather than passive springs. So the bound was left alone and the claw-specific limit became a
warning, `constraints.claw_ride_harshness`, which fires only when there is no band.

It was lowered to **3** on 2026-08-10 for a different reason: to let the search space express a
**deliberately bad** wheel. A design that a good one has to beat is worth more than a bound
that admits only plausible wheels, and at three tips the axle drops `R(1 − cos 60°)` — half a
radius, 30 mm on a 60 mm wheel — which is a genuinely terrible baseline rather than a
marginally worse one. Nothing about #19's finding changed; it is still reported, loudly.

**Three is the floor because below it the model stops meaning anything**, which is a different
kind of limit from a search bound and is enforced in a different place. `polygon_drop_m` at
one spoke is `R(1 − cos 180°)` = 2R, an axle dropping twice the wheel radius;
`second_contact_delta_m` is `R(1 − cos 360°)` = **0**, which reads as "a second claw engages
immediately" on a wheel that has no second claw. `RingSpec` therefore refuses fewer than three
segments outright, and `check_design` calls one or two spokes `DEGENERATE` — geometry that
cannot be built, not a design that scores badly.

## Shared geometric parameters

| Parameter | Symbol | Range | Notes |
|---|---|---|---|
| Outer radius | `R` | **40–90 mm** (re-derived 2026-08-11 from the measured robot) | Floor: the hub must seat the D53 servo horn and leave a claw. Ceiling: judgement — no pipe constraint, the horn rotates, the bed takes R 120; chosen at sane body lift and speed. On this robot **clearance = R + 7.5 mm**, so radius pays twice |
| Width | `W` | 30–70 mm | Capped by track width |
| Rim (shear band) thickness | `t_rim` | 1.2–8 mm, **or exactly 0** | Lower bound from printability; 0 selects the bandless variant below |
| Hub radius | `R_hub` | 0.2–0.6 · `R` | Sets spoke length |
| Tread depth | `d_tread` | 0–4 mm | Maps to friction bracket |
| Sidewall taper | `α` | 0–20° | Lateral grip, support-free printing |

## Compliant-structure parameters (`T3` / `T5`)

| Parameter | Range | Type |
|---|---|---|
| Spoke count `N_s` | 6–36 | integer |
| Spoke thickness `t_s` | 1.2–8 mm | continuous — **the dominant stiffness knob**. The upper bound is set by buckling at the per-wheel load (20.6 N measured; the 6–8 mm figure was derived at the old fictional 24.5 N and errs stiff) |
| Spoke curvature `κ` | −0.03 to +0.03 mm⁻¹ | continuous; sign sets buckling direction |
| Spoke profile | {straight, curved, S-curve, V, honeycomb cell, chevron} | categorical |
| Spanwise pattern | {uniform, tapered, split-pair} | categorical |
| Spoke inclination (out-of-plane) | 0–25° | continuous; couples radial and lateral stiffness |
| Shear band layers | 1–3 | integer |

The space is **conditional**: honeycomb cells introduce cell angle and wall thickness that
other profiles don't have. Ax/BoTorch handles hierarchical spaces; plain scikit-optimize does
not.

### `T3b` — bandless: the spoke tips are the running surface

`t_rim = 0` removes the shear band entirely. It is a **topology switch, not the bottom of
the `t_rim` range** — everything between 0 and 1.2 mm is still rejected as unprintable, and
the screening pre-filter exempts exactly 0 from the bounds check and from the minimum-wall
check. Two extra parameters become live:

| Parameter | Range | Notes |
|---|---|---|
| Spoke phase `φ` | 0–360° | Not searched. Inert with a band; **decisive** without one |

Why it is worth having as the first article: it puts a single spring in the load path
instead of two in series, so an FEA `k_r(δ)` maps onto spoke properties without first
having to separate them from the band's. It is also lighter — 304 cm³ vs 364 cm³ at the
nominal design — and simpler to print.

#### Measured, 2026-08-07

CalculiX 2.23, R 60 × W 30 mm, 6 spokes, `t_s` = 5 mm, hub 20 mm, TPU 95A at 40% infill and
3 walls, δ swept 0 → 6 → 0 mm under displacement control, `φ = −90°` so a tip faces the
indenter. This is the `--tiny` developer preset, **not** the nominal design; it exists to
compare the two topologies at matched geometry, and it reaches only 4.4 N of a 73.5 N target
on the banded side. Treat the ratios as the result and the absolute forces as provisional.

| | 3 mm shear band | bandless, tip at contact |
|---|---|---|
| Flat: force at δ = 6 mm | 4.36 N | 26.9 N, after a peak of **31.4 N at δ = 3 mm** |
| Flat: buckling | none | **limit point at 31.4 N** |
| Flat: `k_r` at peak δ | 1.71 kN/m (stiffening) | −0.55 kN/m (past the limit point) |
| Step edge: force at δ = 6 mm | 3.04 N | 18.31 N |
| Step edge: buckling | none | none; `k_r` softens 2.10 → 1.63 kN/m |
| Step edge: unload loop area | 0.29% | 4.19% (QC threshold is 5%) |
| Flat: p95 spoke stress | 0.08 MPa | 0.47 MPa |

What it costs, and none of it is visible in the CAD:

- **Contact is discrete.** `N_s` tips of width `t_s` replace a cylinder, so the response
  depends on `φ`, and rolling gives `N_s` stiffness cycles per revolution rather than a
  ripple on a continuous curve. Every load case must state its phase.
- **The load path is a strut, not a beam.** The indenter loads one spoke close to axially,
  which is far stiffer than bending a band — and then Euler-buckles it. At equal
  indentation the bandless wheel carries **7.2× the load on the flat plate and 6.0× on the
  step edge**, and the flat case snaps through at 31.4 N. That is **below the 61.2 N the
  buckling constraint demands** (2.5 × nominal; 24.5 N at the time, 20.6 N since the
  2026-08-11 adoption), so this particular bandless design is
  infeasible — `fea_buckling` rejects it. Thicker or more numerous spokes are the lever;
  `P_cr ∝ t³/L²`.
- **Contact pressure is an order of magnitude higher**, over `t_s` rather than a patch.
  On the step edge, where the two sweeps come closest to a comparable state, the bandless
  patch is 81 mm² at 226 kPa mean against 318 mm² at 9.6 kPa. A durability question for
  printed TPU, not just a modelling one.
- **The two topologies cannot be compared at equal load on these sweeps.** Banded flat
  covers 0.4–4.4 N; bandless flat's *first* contact sample is already at 13.5 N. The load
  ranges are disjoint, so there is no load at which both were measured — see
  `fea.results.common_force_n`, which returns `None` rather than clamping both to their own
  ends and reporting a ratio between two states neither solve visited. Closing that gap
  means running the banded case to a much larger δ, not re-reading these results.
- **The ring ROM loses its ring.** Segment-to-segment coupling in
  [`06-compliance-rom.md`](06-compliance-rom.md) §3 *is* the shear band's bending
  stiffness, and here it is zero. The model degenerates to `N_s` independent radial legs.
  That is a legitimate reduced-order model and a simpler one, but it is not the FTire ring,
  and "close the ring with an equality constraint" no longer means anything.

## Material and process parameters

| Parameter | Range | Type | Effect |
|---|---|---|---|
| Shore hardness | {TPU 85A, 95A, 98A, 60D} | categorical | Order-of-magnitude stiffness range |
| Infill density | 15–100% | continuous | Effective modulus, mass, damping |
| Infill pattern | {gyroid, grid, honeycomb, concentric} | categorical | Anisotropy and compression behaviour |
| Wall (perimeter) count | 2–6 | integer | Dominates bending stiffness of thin spokes |
| Layer height | {0.15, 0.2, 0.3} mm | categorical | Interlayer bond strength, fatigue |
| Raster angle | {0°, ±45°, 90°} | categorical | **Anisotropy driver** |
| Print orientation | {flat, on-edge} | categorical | Determines which direction sees weak interlayer bonds |

This is a genuinely coupled space: a thin spoke at 100% infill in 95A behaves nothing like a
thick spoke at 20% infill in 85A, and neither reduces to "an effective modulus" without care.

**Effective-property modelling.** Do not mesh the infill. Use homogenisation: represent each
(pattern, density, wall count) combination as an effective orthotropic hyperelastic material,
calibrated once per combination. Standard RVE approach; collapses a meshing nightmare into a
lookup table.

## Constraints

### Geometric
Clearance, track width, watertight manifold mesh, chassis ground clearance under load — the
last now **load-dependent**, since the wheel squashes.

### Manufacturing (FDM, TPU-specific)
- Minimum wall ≥ 1.2 mm (3 × 0.4 mm nozzle); for TPU prefer ≥ 1.6 mm — thin flexible walls
  print poorly
- Maximum unsupported overhang ≤ 45° (tighter than rigid: TPU droops)
- No unsupported bridges > 15 mm — TPU bridges badly
- Minimum gap between spokes ≥ 2 mm so the nozzle can traverse without dragging
- Bounding box fits the 250 × 225 mm X1C bed; print time ≤ 24 h; material ≤ 450 g. A 170 mm
  wheel in TPU is an overnight print — the old 200 g cap predates the larger platform and
  would have rejected every design that survives the per-wheel load
- Requires direct-drive extruder — a fixed capability, not a variable

**Why two searched thickness ranges start below the TPU wall** (#34, decided 2026-08-11).
`spoke_thickness_mm` and `rim_thickness_mm` are both searched from **1.2 mm**, and TPU cannot
print below **1.6** — so on every TPU design the bottom of each range is infeasible by
construction. That is deliberate, and the same decision for both fields: the range must be
able to *express* a design the wall check rejects, or `spoke_min_wall` / `rim_min_wall` can
never fire and have stopped testing anything. A constraint that no sample can violate is
indistinguishable from a constraint that was deleted, and this project's watch list is a
catalogue of checks that kept passing after they stopped checking.

The cost being traded: samples spent on rejections. Uniformly over each (1.2, 8.0) range the
unreachable band is 0.4/6.8 ≈ **5.9% per field**, and screening rejects those in milliseconds
(invariant 3) rather than in FEA time. If a future optimiser's proposal distribution turns out
to concentrate near the wall and pay materially more than that, the remedy is a
material-dependent bound — more correct and more machinery — not a silent raise of the floor,
which would quietly retire both checks.

### Actuation
Peak torque ≤ 0.7 · stall; achievable top speed accounting for *loaded* rolling radius, which
is smaller than `R` for a compliant wheel and load-dependent. A real effect on gearing and a
classic omission.

### Structural / compliance-specific
- **Static sag:** loaded radius ≥ 0.85 · `R` at nominal load
- **Buckling:** critical load ≥ 2.5 × nominal wheel load. Compliant spokes fail by
  snap-through, not yield
- **Fatigue:** peak cyclic spoke stress below the material fatigue limit with margin. For one
  characterised TPU the fatigue limit was reported at **10.25 MPa**, with cracks originating
  from micropore aggregation and propagating at ~45°
  ([Polymers, 2023](https://www.ncbi.nlm.nih.gov/pmc/articles/PMC9958809/)). Indicative, not
  universal — apply a large safety factor given no in-house material testing
- **Self-contact:** spokes must not collide with each other at maximum deflection. Cheap
  check, easy to forget, produces nonsense FEA when violated

### Implementation
All constraints are a **fast pre-filter returning a violation vector**. An infeasible design
costs 50 ms, not a 6-minute FEA run. See invariant 3 in `CLAUDE.md`.

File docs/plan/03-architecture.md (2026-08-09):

# 03 — System architecture

```
┌──────────────────────────────────────────────────────────────────────┐
│                            ORCHESTRATOR                              │
│        Python · Hydra configs · DuckDB/Parquet experiment store      │
└───┬──────────────────────────────────────────────────────┬───────────┘
    │ design vector θ = (geometry, material, controller)    │ results
    ▼                                                       ▲
┌────────────────────────────┐                              │
│ 1. PARAMETRIC CAD          │  build123d                   │
│    θ → BREP solid          │  → STEP (FEA + archival)     │
│    + constraint pre-filter │  → STL (visual/collision)    │
│    + mass & inertia        │  → region material map       │
└──────────┬─────────────────┘                              │
           ▼                                                │
┌────────────────────────────┐                              │
│ 2a. COMPLIANCE ROM STAGE   │  ◀── the project's core      │
│  quasi-static FEA (offline)│  radial/lateral/torsional    │
│  → stiffness curves,       │  stiffness, contact patch    │
│    contact patch(load),    │  vs load, hysteresis loop,   │
│    hysteresis, buckling    │  buckling load, peak stress  │
│  → fit lumped ring params  │                              │
│  → GP surrogate: θ → ROM   │  (skips FEA after ~300 pts)  │
└──────────┬─────────────────┘                              │
           ▼                                                │
┌────────────────────────────┐                              │
│ 2b. ASSET PIPELINE         │  manifold repair → CoACD     │
│  ROM → segmented ring MJCF │  → hull budget check         │
│  rigid parts → collision   │  → joint stiffness/damping   │
└──────────┬─────────────────┘                              │
           ▼                                                │
┌────────────────────────────┐                              │
│ 3. SIMULATION TIERS        │                              │
│  T0  analytic screen       │  ms      geometric filter    │
│  T1  MuJoCo + ROM ring     │  1–20 s  MAIN WORKHORSE      │
│  T2a quasi-static FEA      │  min     ROM generation      │
│  T2b Chrono ANCF FEA tire  │  hr      verification, top-K │
│  T3  Gazebo + ROS 2        │  RT      integration         │
│  T4  Hardware rig          │  hr      final validation    │
└──────────┬─────────────────┘                              │
           ▼                                                │
┌────────────────────────────┐                              │
│ 4. METRIC AGGREGATION      │  per-scenario → CVaR         │
│                            │  → objectives + constraints ─┘
└──────────┬─────────────────┘
           ▼
┌────────────────────────────┐
│ 5. OPTIMISER               │  Sobol DoE → mixed-variable
│                            │  MOBO (qLogNEHVI) → CMA-ES
└────────────────────────────┘
```

## Caching

Everything is content-addressed: `hash(θ + pipeline version + ROM version)` → cache key. With
an FEA stage in the pipeline this stops being a nicety and becomes essential — a re-run of an
existing design must never recompute.

Cache layers, each independently keyed:

| Layer | Key includes | Typical cost avoided |
|---|---|---|
| CAD geometry | geometry params, CAD module version | seconds |
| FEA results | geometry + material params, FEA config version | minutes |
| ROM fit | FEA results hash, fitting procedure version | seconds |
| Simulation rollout | ROM hash + scenario + seed + sim config version | seconds to minutes |

## Failure handling

Every stage returns a typed result. Failure modes that must be representable without raising:

- geometry infeasible (constraint violation vector)
- mesh non-manifold or repair failed
- convex decomposition exceeded hull budget
- FEA failed to converge
- FEA detected buckling within the operating envelope
- ROM fit residual exceeded tolerance
- simulation diverged or exceeded step budget

A campaign must survive all of these. Log the rate of each as pipeline health metrics.

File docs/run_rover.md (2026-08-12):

# `scripts/run_rover.py` — the whole robot at an obstacle

Four driven wheels, a chassis box with the platform's own mass and inertia, and a step in
front of it. This page explains what every flag does and, more usefully, **what each one is
allowed to change**: some choose the physics, some choose the picture, and some choose only
how long you wait.

Everything here is also in `--help`. The difference is that this page has the figures.

```bash
python scripts/run_rover.py --help
```

> **Read the climb number next to the single-wheel rig's, not instead of it.**
> `run_step.py` asks what one wheel does with a dead weight on it; this asks what four driven
> wheels and a rigid chassis do together. The second flatters a rigid wheel enormously,
> because three wheels push while one climbs. A rigid wheel clears **0.67 R** here against
> **0.33 R** on the rig (it was 1.00 R on the pre-adoption platform, whose 1.19 m/s of
> approach momentum saturated the ladder) — see `docs/plan/TODO.md` #30.

---

## The scene

Side view, to scale in spirit. Everything dimensional is read from
[`configs/robot.yaml`](../configs/robot.yaml), never invented.

```
                                                    ┌──────────────────────────────
      ·····> drive direction                        │  upper ground (top of step)
                                                    │
     ┌───────────────────────┐                      │      ↑
     │       chassis         │ 157 mm high          │  --obstacle-height
     │   8.0 kg + 4x wheels  │                      │      ↓
     └───┬───────────────┬───┘                      │
     R + 7.5 mm ground clearance                    │
        ( )             ( )   R = --radius     ┌────┴──────────────────────────────
  ══════════════════════════════════════════════════════════════════════════
   floor (plane, friction = --friction)        ^
                                               x = 0.80 m, the step face
     |<-- 250 mm -->|                          (fixed; the robot starts at x = 0)
       --wheelbase, from robot.yaml
```

Two things about that box are deliberate and occasionally surprising:

- **The step is an upper ground, not a platform.** Its length is sized from
  `--duration × no-load speed × --radius`, so the robot cannot climb it, cross it and drive
  off the far end — which used to end with a final frame at exactly the ride height, reading
  as "never climbed" when the truth was the opposite.
- **The chassis is a collision geom, not a decoration.** The *ride height* formula is
  `R + 7.5 mm` (the axle-to-belly bracket geometry), but what actually collides is the
  primitive set by default: its bracket plates reach 23 mm *below* the axle line and its
  nose is a dome that rides step edges. `chassis_hit_step` reports any chassis-terrain
  strike, and watching one happen is most of why this model exists.
- **What you see standing on the wheels is the robot's real shell**
  (`configs/pipebot_simplified.stl`), drawn over the box by default and placed by its
  **axle stubs** — the r 7.5 mm cylinders the external wheels mount on. The contact
  chassis under it (the **primitive set** by default since 2026-08-12, the calibrated box
  via `--chassis-collision box`) fades to a ghost but keeps colliding: MuJoCo would
  collide the mesh itself by its convex hull, bridging the legs and belly into one wrong
  underside. `--no-chassis-stl` drops the shell; either way, every number is identical
  (`tests/test_rover.py::TestChassisMesh`).
- **The wheels mount externally, and the track follows the wheel** (2026-08-11): the inner
  face seats against the side plates at ±97.5 mm, so track = `195 mm + width` —
  `PlatformSpec.track_for` — and a wider wheel widens its own support polygon. The 157 mm
  in `robot.yaml` is the original r 22.5 wheels' tucked-under track, kept as reference.

Plan view, with `--approach` doing the one thing it does:

```
   --approach 0                      --approach 15
   ┌─────────┐    │ step face        ┌ ─ ─ ─ ─ ┐   │ step face
   │  ▲      │    │                    ╲   ▲    ╲  │
   │  │ x    │    │                     ╲  │     ╲ │
   └─────────┘    │                      └ ─ ─ ─ ─┘│
   |<- 225 mm ->|                                   ^ still normal to world x
    track = 195 + wheel width        the heading is yawed; the face is not
    (225 at the default 30 mm)
```

`--approach` rotates the *robot's heading*. It does not steer — four non-steered wheels
cannot turn without lateral scrub, and scrub of a segmented capsule ring is validated against
nothing in this project. Values at or past ±90° are refused: the robot would drive along the
face rather than at it, and every metric below would describe a robot that never met the
obstacle. `docs/plan/08-metrics.md` randomises S1 over ±15°, because a step met square is the
easiest case and a real approach is not.

---

## Four wheel models, and which flags reach them

This is the single most important thing to get right before reading a number, because most of
the geometry group is **silently unused** in the default mode.

```
  --compliant   --stl    what is simulated                        what you see
  ───────────────────────────────────────────────────────────────────────────────
     off         off     solid rigid cylinder                     blue cylinder
                         reads: --radius --width --wheel-mass
                         ↑ the default. The rest of the geometry
                           group describes a design nothing builds.

     off         on      solid rigid cylinder                     cylinder + grey
                         (identical numbers to the row above)     CAD shell

     on          off     N segmented bodies on radial slides,     amber capsules
                         spring law from THIS design's FEA
                         reads: the whole geometry + material group

     on          on      same physics as the row above            amber capsules
                         (byte-identical numbers)                 inside a grey
                                                                  CAD shell
```

The chassis shell is independent of both flags — it is on by default in every row and
governed only by `--chassis-stl` / `--no-chassis-stl`.

The overlay is enforced decoration, not a promise: the mesh geom carries
`contype=0 conaffinity=0 mass=0 density=0`, so it collides with nothing and weighs nothing,
and `tests/test_rover.py` asserts every reported number is identical with and without it.
Handing that mesh to a collision system instead is exactly what
[ADR-0002](decisions/0002-reduced-order-model-over-fem.md) exists to prevent.

### What one compliant wheel actually is

```
              spec.n_segments bodies, each on a radial slide
                        (+ optionally a hinge at its root)
                                  │
              ────────  ╭─╮  ────────
                    ╭─╮ │ │ ╭─╮            each capsule: mass = (wheel_mass - hub) / N
                 ╭─╮    ●    ╭─╮           each slide:   force from the FEA spring law
                    ╰─╯ │ │ ╰─╯            hinge pivot:  one capsule radius inboard of
              ────────  ╰─╯  ────────                    the true claw root
                              ↑
                          ● = hub, on the driven axle hinge
```

**The ring is planar.** Each one lies in its own x–z plane and its segments move radially and
in-plane-tangentially. A rover rolls, yaws, and drops wheels off edges — all of which load a
wheel *out of plane*, where the ring is perfectly rigid. That, plus the unvalidated element
above second-claw engagement (`+62.7%` with a slide, `−49.5%` with a hinge, against the FEA),
is why `--compliant` prints a banner and why this is filed as a **picture, not a
measurement** (TODO #30, #31).

---

## The pipeline a run goes through

Each stage announces itself and reports its own wall time; the long ones carry a progress bar
on **stderr**, so piping stdout to a file leaves clean output and the bar still finds the
terminal.

```
   flags
     │
     ├─ --config ─────────────► load_platform()      mass, dims, inertia, wheelbase,
     │                                               track, clearance, motor curve
     │
     ├─ --compliant ──────────► FEA  (CalculiX)      ── minutes cold, seconds cached
     │    --plane-strain          whole-wheel sweep      the run says which it got
     │    --delta-max             + one-claw sweep
     │    --n-points                     │
     │    --law/--segments               ▼
     │    --cache/--threads         segment spring law
     │    --tangential ───────► tangential FEA sweep ──► hinge / slide element
     │                                    │
     ├─ --stl ────────────────► build123d ──► STL     ── decoration only
     │    --mesh-alpha                     │
     │                                     ▼
     ├─ --obstacle-height ────►  build MJCF  ──►  simulate  ──► RoverResult
     │  --friction --approach                        │
     │  --throttle --duration                        │
     │                                               │
     └─ --render ──────────────────────────────────► frames ─► MP4 / GIF / sheet
          --fps --pixels --out                                  (--no-mp4, --no-gif)
```

A missing optional dependency degrades rather than stops: no OCCT means no overlay and the
simulation runs unchanged; no `ffmpeg` means no MP4 and the GIF still gets written.

---

## The flags, group by group

### The obstacle and the platform

| Flag | Default | What it does |
|---|---|---|
| `--config` | `configs/robot.yaml` | The robot. Chassis mass, dimensions, inertia, wheelbase, track, ground clearance and the motor's torque–speed curve. Nothing in this script invents any of them. |
| `--obstacle-height` | `60.0` mm | Height of the step. Reported back as a fraction of wheel radius, which is the only form worth comparing across radii. **Exactly 0 is a different scenario** — see [flat ground](#flat-ground-the-harshness-scenario). |

`--obstacle-height` was named for the obstacle rather than `--step`, which in a MuJoCo script
also means the integration step and had to be disambiguated by context every single time it
was read.

### Geometry (mm) — a design, only read when something builds it

These are the shared `gen_wheel.py` flags. Each searched one quotes its own screening bound,
read from `PARAM_BOUNDS` rather than typed, so the help and the check cannot drift apart.

| Flag | Bound | Notes |
|---|---|---|
| `--radius` | 60–100 mm | Also capped by the chassis wheel well and the print bed. |
| `--width` | 30–70 mm | Plane-strain FEA force scales linearly with this. |
| `--rim-thickness` | 1.2–8 mm, **or exactly 0** | 0 is a *topology switch*, not the bottom of the range: no shear band, and the spoke tips become the running surface. That is the `T7` claw family. |
| `--hub-radius` | mm | Sets the claw root, so claw length is `radius − hub_radius`. |
| `--bore-radius` | mm | Fixed by the drivetrain, not searched. |
| `--spokes` | 3–36 | **Bandless, this is also the ring's segment count.** |
| `--thickness` | 1.2–8 mm | At the **root**. |
| `--curvature` | ±0.03 1/mm | Signed: which way the spoke bows, and so which direction of drive torque stiffens it. |
| `--profile` | straight / curved / s_curve | Spoke centreline family. |
| `--claw-taper` | 0.25–1 | Tip thickness as a fraction of root. 1.0 is a uniform strut. The minimum-wall check reads the **tip**, so a thick root with an aggressive taper is still rejected. |
| `--tread-depth` | 0–4 mm | 0 is a smooth tread. |
| `--spoke-phase` | degrees | Only matters without a band, where contact is discrete. `-90` puts a tip at the contact point. |

**These are easier to see than to read.** `scripts/plot_geometry.py` draws every one of them
across its own range, with each design's screening verdict under it:

```bash
python scripts/plot_geometry.py --only taper --only spokes --format pdf
```

Two failure modes worth naming, because both read as innocuous:

- **Setting geometry without `--compliant` or `--stl` does nothing at all.** The run is four
  rigid cylinders and only `--radius`, `--width` and `--wheel-mass` are consulted.
- **A rejected design prints a violation list, not a stack trace.** `envelope_radius`,
  `print_bed` and `bounds_outer_radius_mm` all reading `infeasible` means the wheel is too big
  for the chassis well, too big for the print bed, and outside its own search bound —
  typically one root cause, `--radius`, reported three times.

### Material — density *and* stiffness, by two different laws

| Flag | Default | Notes |
|---|---|---|
| `--material` | `TPU_95A` | Filament preset: base density plus hyperelastic coefficients. |
| `--infill` | `0.4` | Knocks mass down **linearly** and stiffness down by a **Gibson–Ashby power law**. Deliberately not the same curve; anyone reading both would otherwise assume one is a bug. |
| `--pattern` | `gyroid` | Sets the packing efficiency behind the knock-down. |
| `--walls` | `3` | A feature thinner than `2 × walls` prints solid, `--infill` then does nothing, and that is reported as a warning. |

### The run

| Flag | Default | Notes |
|---|---|---|
| `--wheel-mass` | `300.0` g | One whole wheel. Held equal between rigid and segmented, so the comparison is at matched mass. |
| `--throttle` | `1.0` | Fraction of stall torque at all four axles. |
| `--duration` | `6.0` s | Also sizes the step box. |
| `--friction` | `1.0` | TPU on concrete. Generous on purpose, so a failed climb is not merely a traction failure. |
| `--approach` | `0.0`° | Heading yaw. Refused at ±90 and beyond. |
| `--washboard` | `0.0` mm | S7: peak-to-trough height of a sinusoidal corrugation. Needs `--obstacle-height 0`; refused alongside a step. |
| `--wavelength` | `100.0` mm | The corrugation's wavelength. Quote every S7 number with both. |
| `--slope` | `0.0` ° | **S2**: uphill gradient, implemented by tilting *gravity* — same physics as an infinite ramp, no entry transient. Metric: sustained speed; sweep gradients for the max sustained gradient. Rigid R 60 holds 10° at 0.38 m/s and backslides at 40° (traction-limited, μ = 1). |
| `--gap` | `0.0` mm | **S3**: a 150 mm-deep trench across the ground, near edge at `step_x`. The floor plane becomes two slabs (a plane cannot have a hole). `crossed` needs the whole body at ride height on the far side; a wheel that drops in stays in. |
| `--rubble` | `0.0` mm | **S4**: tallest rock of a procedural 1.2 m strip; every rock is buried (no floating steps) and none exceeds the asked height, by test. `--rubble-seed` **is** the terrain — same seed, same field, to the bit. One seed is one terrain: sweep seeds before believing a number. Needs `--duration` ≥ ~8 s to reach the far side at this drivetrain's speed. |
| `--spin` | off | **S6 proxy**: left and right sides driven opposite; reports steady yaw rate and scrub energy. **Quarantined by TODO #38** — the ring is laterally quasi-rigid by structure, but tip-level scrub is validated against nothing, so this ranks designs only after #38's checks land. |

Every scenario flag needs `--obstacle-height 0`, and exactly one scenario per run — any
pair is refused by name (`RoverSpec` exclusivity; the suite scores S1–S8 as separate rows).
On any run that travels ≥ 0.2 m the result also carries **`cost_of_transport`** (S5,
objective 2): `E/(m·g·d)` over the driving phase — 0.01 for the rigid cylinder on the flat,
0.18 climbing 10°. On compliant wheels it inherits `TPU_LOSS_FACTOR`'s caveat wholesale.
| `--sweep` | off | Instead of one run, ladder 10 mm to 2.1 R in 10 mm buckets. |

The drive is the platform's own linear torque–speed curve, clipped so a motor never brakes:

```
   torque
     │
  τ_stall ●───╮                τ = throttle · τ_stall · (1 − ω/ω_0),  floored at 0
     │         ╲
     │          ╲              Clipped rather than allowed negative: a motor commanded
     │           ╲             forward and overspeeding would brake, and a braking wheel
     │            ╲            rolling off a step looks like a climb failure caused by
     0 ───────────●──────      the wheel rather than by the drive model.
     0            ω_0    ω
```

The first `settle_s` (0.8 s) of every run commands **no torque at all**. The robot is dropped
a whisker onto the floor and must come to rest first, or the run measures a bounce. This is
why `--duration` must exceed it, and why `distance_m` is measured from the end of settling.

### Compliant wheels

| Flag | Default | Notes |
|---|---|---|
| `--compliant` | off | Four segmented rings instead of four cylinders. Needs CalculiX. |
| `--law` | `claw` | Where the segment law comes from — see below. |
| `--segments` | `24` | Ring resolution. **Ignored by `--law claw`**, where the segments *are* the claws and the count is `--spokes`. |
| `--tangential` | off (bare flag = `hinge`) | A second in-plane freedom per claw. |
| `--plane-strain` | off | The 2-D screening FEA tier: seconds instead of hours. |
| `--delta-max` | `0.012` **METRES** | How deep the FEA presses. Note the unit — every geometry flag above is millimetres. |
| `--n-points` | `10` | Samples per branch. Too few cannot resolve a curve that peaks early. |
| `--cache` | `data/cache/fea` | Content-addressed. A hit is seconds, a miss is minutes; the run says which it got. |
| `--threads` | `4` | Changes how long the answer takes, not what it is — so it is excluded from the cache key. |

**`--law` is the choice that moves the answer most.**

```
  --law claw     press ONE claw in FEA. The measured curve IS the segment law:
                 no fit, no deconvolution. The whole-wheel curve is then spent on
                 a HELD-OUT check instead of being training data.
                 Bandless designs only.  ← the default, and the right one

  --law table    press the WHOLE WHEEL, then deconvolve that curve into N
                 independent segment laws, piecewise linear.

  --law cubic    same deconvolution, fitted to a cubic.
```

The deconvolution is ill-posed when a band carries load between segments, which is an argument
*for* the claw family, where there is no deconvolution to do. Below second-claw engagement the
whole wheel **is** one claw, and the claw law agrees with the whole-wheel curve to **0.036%**.
Above it the ring is not validated at all.

**`--tangential` picks an idealisation, and the two bracket the truth from opposite sides.**

```
  slide                                  hinge  ← the right element
     claw tip slides tangentially           whole claw rotates about its root
     tip moves OUTWARD as it splays         tip moves INWARD as it splays
     FEA at 36 mm travel:  −13.9 mm         FEA at 36 mm travel:  +22.6 mm
                    measured truth: +19.7 mm ────────┘
     kept only as the thing the hinge is compared against
```

Above second-claw engagement, at 9.6 mm, the slide reads **+62.7%** and the hinge **−49.5%**
against the same FEA. Two idealisations straddling the truth from opposite sides is not a law
problem; it is the missing flank contact, filed as TODO #31.

### CAD overlay

| Flag | Default | Notes |
|---|---|---|
| `--stl` | off | Draw the real CAD geometry over each wheel, translucent grey. Needs build123d; the STL is cached under `data/wheels` by design hash. |
| `--mesh-alpha` | `0.40` | 0 invisible, 1 solid. |
| `--chassis-stl` | `configs/pipebot_simplified.stl` | The robot's shell, drawn over the chassis box and placed by its **axle stubs** (r 7.5 cylinders in the model, stations 103.5/353.5 mm — wheelbase 250.03 against the platform's 250, the cross-check). The box stays the contact geom, faded to a ghost. A missing file downgrades to the box with a note. |
| `--chassis-collision` | `primitives` | **A physics switch, not a rendering one.** `primitives` (the default since 2026-08-12) collides the shapes read off the simplified model — the r 72.5 pipe, the r 55 dome nose, and the bracket plates whose points reach **23 mm below the axle line**. Lossless: every non-stub mesh vertex lies on or inside the primitive union, pinned by test. `box` is the flat-bellied box calibrated to the hand-measured clearance (belly at R + 7.5), kept for comparison and pre-flip continuity. Measured on the R 85 ladder: 60/80 mm byte-identical (the chassis never touches), 100 mm a different failure — the box hard-stops at 0.9° pitch where the dome rides the edge to 24.6°. The plates' low points are CAD facts not yet confirmed on hardware; if the hand check contradicts them, the box's measurement wins. Never mix the two in one comparison. |
| `--no-chassis-stl` | off | The plain chassis box, as before. |

The colours are load-bearing, not decorative:

```
   amber capsules  ← the physics. The ring's segments; what the numbers describe.
   grey shell 40%  ← decoration. The shape the physics stands for.
   white shell     ← the robot's real body. Also decoration; the ghost box under
                     it is what actually collides, belly strikes included.
```

Two honesty notes on the shell. Its **axle stubs** run from the side plates into the
simulated wheels' hubs — that is where the external wheels actually mount, and the stub
axes are what the mesh is registered by. And the shell's overhang is **asymmetric** —
~105 mm at the nose against ~71 mm at the tail, where the contact box models a centred
88/88 — so on a nose-in run the shell visibly leads the box. The box is the physics; the
mismatch is the measured gap between the platform model and the machine, drawn rather than
hidden.

Amber was chosen to read against the grey floor, the brown step and the translucent shell.
Before that, `ring_bodies` emitted no `rgba` at all, so the capsules took MuJoCo's built-in
geom colour — a washed olive-green. The one colour in the render that had not been chosen was
the one carrying the result.

### Output

| Flag | Default | Notes |
|---|---|---|
| `--render` | off | Write MP4, GIF and a contact sheet to `--out`. |
| `--no-mp4` | off | Skip the H.264 video (needs `ffmpeg` on PATH). |
| `--no-gif` | off | Skip the GIF. The MP4 is ~13× smaller and full colour, so `--no-gif` is usually what you want. |
| `--fps` | `25` | Used **both** to sample the simulation and to play it back, so the video runs at real speed. |
| `--pixels` | `900` | Frame width; height is 9/16 of it. |
| `--out` | `data/renders` | Where the three files land. |

---

## Reading the result

```
robot: piperobot-426x231, 8.0 kg chassis + 4 x 300 g wheels, 426x231x157 mm
       wheelbase 250 mm, track 157 mm, R 85 mm, ride 171 mm
drive: 6.0 N·m stall x4 at 1.00 throttle, 6.6 rad/s free (0.56 m/s)
       NOTE meta.frozen is false — these are estimates, not a measured robot
-> simulating 6.0 s at a 60 mm obstacle
   0.6s  (climbed)

obstacle 60 mm (0.71 R)
  climbed            True
  travelled          2565 mm
  final clearance    171.0 mm (standing is 171 mm)
  peak pitch / roll  13.9° / 0.33°
  stability margin   +0.72 (1 = level; 0 = CG over the wheel line; crit 49°/36° pitch/roll)
  chassis hit step   False
  axle work          16.6 J
```

That `meta.frozen is false` line is not noise. The chassis envelope is a requirement, but its
mass, motors, battery and inertia are still estimates — so every number above inherits that.

**`climbed` has two conditions and each was wrong alone.** The chassis centre must be a full
half-length past the face *and* within a fifth of its ride height of where it would stand:

```
                              ┌─────────┐  ← climbed: past the face AND at ride height
                    ┌───┐     │         │
   ┌─────┐         ╱│   │     └─────────┘
   │     │        ╱ └───┘  ↑             ┌──────────────────
   └─────┘       ╱         │             │
  ═══════════════──────────┴─────────────┘
   not climbed   reared up:              x > step_x + L/2
                 past the face by x,     and |z − h − ride| < 0.2·ride
                 and 113 mm too high.
                 The x test alone passes it.
```

- **`final clearance`** is height above the *upper* ground. Near the ride height means it is
  standing on the step; near minus the obstacle height means it never left the floor.
- **`peak roll`** should be ~0 on a square approach. Non-zero there means the solver, not the
  terrain.
- **`chassis hit step`** is bellying out (or nosing in) rather than climbing — a real
  outcome for a belly at `R + 7.5 mm`, not an error.

Exit codes: `0` cleared (or `--sweep` finished), `1` did not clear or the run failed, `2` a
dependency or a config file is missing.

### `--sweep`

```
  rigid           40 mm  [####........] 10-120 mm  (0.67 R)
                          │└──────────── did not clear
                          └───────────── cleared
                                          ↑ ladder span, then the answer as a fraction of R
```

(That is an `--radius 60` sweep: `2.1 R` = 126 mm, so the ladder runs 10 → 120 mm.)

**Quote the answer as a bucket, not a millimetre.** The ladder steps in 10 mm and a 1% change
in the segment law can move the answer a whole bucket, so a one-bucket gap between two designs
is not a ranking. The profile is printed rather than just the maximum because the predicate is
not monotone — a bounce reads as a climb otherwise. `AT THE SWEEP CEILING` means the true
value is at least the reported one.

---

## Flat ground: the harshness scenario

`--obstacle-height 0` emits **no obstacle at all** and measures **objective 3** from
`docs/plan/08-metrics.md`: RMS vertical chassis acceleration. It exists because the step-climb
number on this robot discriminates only coarsely — three driven wheels push while one
climbs. On the measured platform the ladder separates compliant from rigid (claws 1.00 R
against the cylinder's 0.67 R, 2026-08-11) but still not claw counts from each other: 6 and
12 claws tie. Within the family, harshness is the axis.

A bandless wheel runs on discrete tips, so it is a **polygon**, and the axle rises and falls
once per tip. That is the cost compliance is supposed to buy back:

```
   rigid polygon, n tips              compliant claw, same n
                                                                axle
      ╭──╮      ╭──╮                     ╭──╮      ╭──╮          height
     ╱    ╲    ╱    ╲                   ╱    ╲    ╱    ╲            │
    ╱      ╲__╱      ╲                 ─        ──       ─          │  ripple
                                                                    ↓
    drop = R(1 − cos π/n)              the claw deflects INTO the
    per half pitch                     gap, so the ripple is smaller
                                       — but only if it deflects by
                                       an amount comparable to the drop
```

Three numbers are printed together, and they come from three different places on purpose:

| Line | Where it comes from | What it is |
|---|---|---|
| `ride harshness` | **MuJoCo**, `qacc` on the chassis free joint | RMS m/s² over the steady window. The measurement. |
| `polygon drop` | **closed-form trigonometry**, `R(1 − cos π/n)` | The rigid limit. No FEA, no dynamics. |
| `loaded ripple` | **the ring**, solving `F(δ, ψ) = load` per phase | Peak-to-peak axle travel with the fitted law and no dynamics at all. |

A model needs at least one check against a number it did not produce. The polygon drop and the
loaded ripple are that check for the harshness measurement — if one moves and the others do
not, stop.

### Measured, R 60 mm, taper 0.6, 6 s at full throttle

| wheel | harshness | polygon drop | loaded ripple | axle work | mean speed |
|---|---|---|---|---|---|
| 3 claws | **22.6** m/s² | 30.0 mm | 29.1 mm | 46.1 J | 0.81 m/s |
| 6 claws | **10.3** m/s² | 8.0 mm | 7.4 mm | 41.7 J | 0.71 m/s |
| 12 claws | **5.0** m/s² | 2.0 mm | 1.5 mm | 12.0 J | 0.83 m/s |
| rigid cylinder | **0.0** m/s² | — | — | 3.9 J | 0.84 m/s |

A **4.5× spread** where the step-climb sweep gave none. Cost of transport separates them too:
the 3-claw wheel spends 12× the axle work of the cylinder to cover the same ground.

Note the ripple against the drop: at 12 claws compliance cuts the ripple 25% below the rigid
polygon, at 3 claws it cuts it 3%. A wheel only rides smoother than its own polygon if it
deflects by something comparable to the drop, and at 24.5 N per wheel this design deflects
about 1 mm.

### Three caveats that travel with these numbers

- **The rigid comparator is a smooth cylinder, so 0.0 is not a wheel anyone could print.**
  It is the floor of the metric, there to prove the metric is not measuring the solver.
- **Fewer claws extrapolate the segment law, and the run says so.** A 3-tip R 60 wheel has a
  30 mm polygon drop; the FEA sweep behind the law runs to `--delta-max`, 12 mm by default,
  and a tabulated law extrapolates on its last slope without complaint. The `EXTRAPOLATED`
  warning fires with the ratio. Widening the sweep 12 → 18 mm moved the 3-claw answer
  24.65 → 22.64 m/s², about 8%, so the *ranking* survives — and **35 mm cannot be measured at
  all**: CalculiX diverges at 10 cutbacks, which is itself a statement about a claw pressed
  half its own radius.
- **This objective has no counter-pressure of its own.** Harshness alone ranks 36 claws above
  12 above 3, monotonically and forever. The pressure back the other way lives in the other
  three objectives — mass, obstacle capability, cost of transport — which is exactly why
  [ADR-0006](decisions/0006-multi-objective-not-scalarised.md) forbids scalarising them into
  one number.

### The washboard (S7): where compliance wins outright

On flat ground the rigid cylinder's 0.00 m/s² is unbeatable. `--washboard` adds a sinusoidal
corrugation — a strip of boxes, entered at a trough so the doorstep is a ramp — and there the
rigid wheel must follow the ground while a compliant one need not:

```
   10 mm peak-to-trough, R 60 mm, full throttle

   wavelength      60 mm    100 mm    200 mm    400 mm
   rigid           40.6      43.3      36.5      33.8   m/s² RMS
   12-claw          6.4       6.3       6.2       7.1
   ratio            6.3x      6.9x      5.9x      4.8x
```

The compliant wheel is also **not slower** (0.67–0.86 m/s against the rigid 0.61–0.78), so it
is not smooth by being slow — and the 3-claw wheel reads 10.0 against the 12-claw's 6.3, so
the metric still ranks within the compliant family. One caveat travels with the magnitudes:
20–53% of those runs have two claws sharing load, where the ROM's element is unvalidated
(TODO #31), and the run says so on its own output. The **sign** is the result.

```bash
python scripts/run_rover.py --obstacle-height 0 --washboard 10 --wavelength 100 \
    --compliant --radius 60 --rim-thickness 0 --spokes 12 --thickness 6 \
    --claw-taper 0.6 --spoke-phase -90 --plane-strain --law claw
```

```bash
# The harshness ladder: a deliberately bad wheel against a good one.
for n in 3 6 12; do
  python scripts/run_rover.py --obstacle-height 0 --compliant --radius 60 \
      --rim-thickness 0 --spokes $n --thickness 6 --claw-taper 0.6 --spoke-phase -90 \
      --plane-strain --law claw
done
```

---

## Worked commands

```bash
# One run against a 60 mm step, rigid wheels, numbers only.
python scripts/run_rover.py --obstacle-height 60
```

```bash
# The tallest obstacle an 85 mm rigid wheel clears, as a profile.
python scripts/run_rover.py --radius 85 --sweep
```

```bash
# Four segmented claw rings from this design's own FEA, the real CAD shape ghosted
# over them, filmed. Needs CalculiX for the ring and build123d for the overlay.
python scripts/run_rover.py --compliant --stl --radius 60 --rim-thickness 0 --spokes 12 \
    --thickness 6 --claw-taper 0.6 --spoke-phase -90 --plane-strain \
    --law claw --tangential hinge --obstacle-height 40 --render --no-gif
```

```bash
# A deliberately bad wheel: three claws, so the axle drops 30 mm between tips.
python scripts/run_rover.py --compliant --radius 60 --rim-thickness 0 --spokes 3 \
    --thickness 6 --claw-taper 0.6 --spoke-phase -90 --plane-strain --law claw --sweep
```

On the pre-adoption platform that last one cleared **exactly what a 12-claw wheel and a
plain rigid cylinder clear** — 1.00 R for all three, the step-climb metric saturating on
approach momentum. The measured platform (2026-08-11) de-saturated it: the rigid cylinder
drops to 0.67 R and the claws hold 1.00 R, so compliant-vs-rigid now separates — but 3, 6
and 12 claws still tie with each other (and the 3-claw number is 2.4× extrapolated past its
law). Ranking *within* the family is still the job of
[flat ground](#flat-ground-the-harshness-scenario) and the washboard, which separate the
same wheels 4.5×. TODO #30 has the full table.

---

## Related

- [`scripts/run_step.py`](../scripts/run_step.py) — the single-wheel rig. One wheel, a dead
  weight, five signatures. The number to read alongside this one.
- [`docs/plan/TODO.md`](plan/TODO.md) — #30 (compliant-vs-rigid on the rover) and #31 (the
  claw's flank contact) both gate what this script's compliant mode is allowed to claim.
- [`docs/plan/08-metrics.md`](plan/08-metrics.md) — the scenario suite this obstacle is one
  rung of.
- [ADR-0002](decisions/0002-reduced-order-model-over-fem.md) — why FEA never runs in the loop,
  and why the CAD mesh here is decoration.

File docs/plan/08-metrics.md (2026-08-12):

# 08 — Scenarios, objectives and metrics

## Scenario suite

| Scenario | Randomised over | Primary metric |
|---|---|---|
| **S1 Step** | height 10–200 mm, edge friction, approach angle ±15° | Step height at P(success) = 0.9 |
| **S2 Slope** | incline 5–40°, friction 0.3–1.0 | Max sustained gradient |
| **S3 Gap** | width 20–200 mm | Max gap crossed |
| **S4 Rubble** | procedural rock field, size/density | Traverse success rate, mean speed |
| **S5 Flat sprint** | surface friction, 10 m | **Cost of transport (hysteresis-sensitive)**, top speed |
| **S6 Path track** | ~~figure-8 / slalom~~ **spin-in-place proxy** (decision 2026-08-11): yaw rate at differential torque + per-wheel scrub energy | Turn capability and turning cost. Full path-tracking deferred — it sits behind #38's lateral validation *and* a controller, and would measure the controller as much as the wheel. Revisit if designs differ meaningfully on the spin test |
| **S7 Washboard** | sinusoidal ripple, amplitude and wavelength | **RMS chassis acceleration — where compliance wins** |
| **S8 Sustained load** | nominal + 2× load, long duration | Sag, buckling margin, predicted fatigue cycles |

**Build status 2026-08-12**: S1, S2, S3, S4, S6 (as the spin proxy, quarantined by #38)
and S7 all run in `sim/rover.py` / `run_rover.py`, and S5's cost of transport is computed on
every run that moves; what S5 still lacks is the dedicated 10 m sprint protocol, and S8
remains FEA-side constraints only. Terrain seeds exist for S4 (`rubble_seed`); the
seeds-times-CVaR aggregation over the suite is Phase 2's remaining half.

**S5 and S8 are the anti-degenerate scenarios for compliance.** Without S5 the optimiser makes
everything maximally soft; without S8 it makes everything soft enough to collapse.

## Objectives — multi-objective, never scalarised (ADR-0006)

1. **Maximise** obstacle capability index (S1–S4 normalised)
2. **Minimise** cost of transport (S5/S6) — dominated by hysteretic loss for soft wheels
3. **Minimise** ride harshness, RMS vertical chassis acceleration (S5–S7) — compliance's
   payoff axis
4. **Minimise** wheel mass
5. **Maximise** the stability margin (S1–S4, S7) — worst-moment distance to static tip-over,
   ``1 − max(|pitch|/pitch_crit, |roll|/roll_crit)`` with the critical angles derived from
   the platform's own CG height, wheelbase and track
   (`PlatformSpec.tipover_angles_rad`). Added 2026-08-11: "stability" for this project is
   *not tipping over on obstacles and slopes* — rollover and pitch containment — which
   harshness (objective 3, a comfort axis) does not measure. Aggregated like everything
   else, CVaR at 25% over seeds, which for a worst-moment property is exactly the right
   emphasis: a design that is upright on average and tips on the worst seed has tipped.

Report the 4-D Pareto front. Select finalists by hypervolume contribution and by named
preference profiles (obstacle-first, efficiency-first, balanced).

## Logged but not optimised

Slip ratio, peak motor current, **loaded rolling radius**, **contact patch
area vs load**, **peak spoke stress**, **predicted fatigue cycles**, **buckling margin**,
print time and mass, solver warning count, contact-impulse spectrum, FEA convergence
iterations, ROM fit residual.

## The threshold-metric fix

"Maximum step height cleared" is a **discontinuous, noisy threshold**. Bisection on a
stochastic simulator gives a jittery signal that poisons a GP surrogate.

**Instead:** evaluate a fixed ladder of heights (10 heights × 8 seeds), fit a logistic success
curve, and report the **height at which success probability crosses 0.9** as a continuous
quantity with an uncertainty estimate. This one change materially improves optimiser
convergence.

## Aggregation

Each design is evaluated over `k ≥ 8` terrain seeds **×** `m ≥ 4` material realisations.
Aggregate with **CVaR at 25%** (mean of the worst quartile), not the mean. This produces
robust designs and is what hardware transfer requires. (Invariant 7.)

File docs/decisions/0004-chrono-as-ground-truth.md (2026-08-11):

# ADR-0004 — Project Chrono as ground truth, never in the loop

**Status:** superseded in its gating role by ADR-0008 (2026-08-11) — hardware is the ground truth; Chrono remains the documented option for a sim-to-sim cross-check
**Date:** 2026-08-04
**Depends on:** ADR-0002

## Context

The reduced-order compliance model (ADR-0002) is an approximation. Its validity is the central
claim of the project, so it must be checked against something more trustworthy than itself.
Hardware validation happens only in Phase 4; a computational reference is needed from Phase 1.

## Decision

Use **Project Chrono with ANCF (or Reissner) shell FEA tires** as the computational ground
truth. Never in the inner loop.

Three uses:

1. **ROM validation** (Phase 1 gate) — does the ring model reproduce Chrono's dynamic
   response ranking?
2. **Cross-engine rank correlation audit** (Phase 3 gate) — Spearman ρ between ROM and Chrono
   rankings on top-50 + 20 random designs. ρ > 0.7 to proceed; ρ < 0.4 means stop and fix the
   model.
3. **Final verification** of top designs before printing.

## Why Chrono specifically

Chrono::Vehicle offers full finite element tire representations via ANCF or Reissner shell
elements — the most accurate and most expensive tire models available — and can account for
**simultaneous deformation in tire and soil**. There is a documented `ANCFTire` class and
shipped co-simulation test programs (`test_VEH_HMMWV_Cosimulation`,
`test_VEH_tireRig_Cosimulation`) coupling deformable tires to granular terrain via explicit
force–displacement co-simulation on non-blocking parallel threads.

The exact combination needed — a flexible wheel, on rigid or deformable ground, inside a full
vehicle model — already exists, is validated, and is open source. Nothing else in the
candidate set offers this.

## Consequences

- A second simulation stack must be stood up and maintained, with its own asset pipeline from
  the same STEP geometry. Budget for this in Phase 1.
- The Phase 3 cross-engine gate becomes a genuine go/no-go, not a formality.
- Deformable terrain becomes *available* (Chrono CRM/SCM/DEM) without being *in scope*.
  **Hard rule: no deformable terrain in the inner loop before Phase 3** — see risk R11. Note
  also that SCM is only valid for small sinkage, low slip and near-cylindrical wheels without
  lugs, so lugged or compliant wheels on soil require CRM or DEM, not SCM.

## Revisit if

- Chrono ANCF proves too unstable or slow even for tens of designs — fallback would be
  single-wheel FEA co-simulation rigs only, dropping the full-vehicle reference.
- Hardware data becomes plentiful enough to serve as the primary reference, demoting Chrono
  to a secondary check.

## References

- [Chrono::Vehicle tutorial — tire model hierarchy](https://www.projectchrono.org/assets/slides_3_0_0/5_Vehicle/1_ChronoVehicle.pdf)
- [Chrono ANCFTire class reference](https://api.projectchrono.org/classchrono_1_1vehicle_1_1_a_n_c_f_tire.html)
- [High-fidelity vehicle mobility: nonlinear FE tires on granular material](https://www.sciencedirect.com/science/article/abs/pii/S0022489816301173)

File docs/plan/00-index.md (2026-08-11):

# Project plan — index

Automatic optimisation of the 3D layout of compliant (TPU) wheels for a mobile
terrestrial robot.

Read `01` and `02` for orientation. `06` is the technical core. `16` is what to do first.
**`TODO.md` is what is left** — the numbered open list, read before picking up work.

| File | Section | Read when |
|---|---|---|
| [TODO.md](TODO.md) | **Open work, numbered** — plus standing gaps in what is modelled | Picking up work; before proposing something new |
| [01-assessment.md](01-assessment.md) | Honest assessment, prior work, failure modes | Starting out; questioning scope |
| [02-research-questions.md](02-research-questions.md) | Research questions and novelty positioning | Writing, or defending the contribution |
| [03-architecture.md](03-architecture.md) | System architecture, caching, failure handling | Implementing any pipeline stage |
| [04-design-space.md](04-design-space.md) | Topology families, parameters, materials, constraints | Adding a family; writing the CAD layer |
| [05-simulators.md](05-simulators.md) | Engine-by-engine capability analysis and tiering | Considering a simulator change |
| [06-compliance-rom.md](06-compliance-rom.md) | **Technical core** — reduced-order compliance modelling | Almost always |
| [07-materials.md](07-materials.md) | TPU characterisation without equipment; cyclic softening | Material modelling; hardware protocol |
| [08-metrics.md](08-metrics.md) | Scenario suite, objectives, logged metrics | Implementing evaluation |
| [09-optimiser.md](09-optimiser.md) | Optimiser design, baselines, termination | Implementing the search |
| [10-reality-gap.md](10-reality-gap.md) | Domain randomisation, artifact audits, validity gates | Before trusting any result |
| [11-phases.md](11-phases.md) | Phased plan with go/no-go gates | Planning; at every gate |
| [12-risks.md](12-risks.md) | Risk register | At every gate |
| [13-engineering.md](13-engineering.md) | Engineering practices | Setting up infrastructure |
| [14-cad-toolchain.md](14-cad-toolchain.md) | CAD choice and asset pipeline | Writing the CAD/asset layer |
| [15-extensions.md](15-extensions.md) | Extensions once the core works | After the Phase 3 gate, not before |
| [16-first-week.md](16-first-week.md) | Concrete one-week feasibility spike | **Now** |
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

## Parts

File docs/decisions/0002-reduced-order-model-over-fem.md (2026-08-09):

# ADR-0002 — Reduced-order compliance model, not FEM in the loop

**Status:** accepted
**Date:** 2026-08-04
**Depends on:** ADR-0001, ADR-0004, ADR-0005

## Context

Compliant TPU wheels must be evaluated in closed-loop dynamic simulation thousands of times.
Full FEM of the wheel inside that loop is roughly 10³–10⁵× too slow — a realistic campaign
would complete on the order of 40 designs in six months. Rigid-body simulation, at the other
extreme, cannot represent contact-patch growth, load-dependent rolling radius, hysteretic
loss, or edge envelopment — the entire set of effects the project exists to study.

## Decision

Model each compliant wheel as an **`N`-segment ring of rigid bodies** (initially `N = 24–48`)
connected to the hub and to each other by joints whose stiffness and damping are **fitted
offline to quasi-static FEA load cases**. Run that ring model in MuJoCo at full speed.

After ~300 FEA runs, fit a surrogate mapping **design parameters → ROM parameters**, so
subsequent candidates skip FEA entirely.

**FEA never runs inside the optimisation loop.** It is an offline, cached, per-design
pre-processing step. Recorded as invariant 1 in `CLAUDE.md`.

## Alternatives considered

**Full FEM in the loop (Chrono ANCF, MuJoCo flex) — rejected on throughput.** Retained as a
verification tier only (ADR-0004).

**Rigid wheel + soft contact (`solref`/`solimp`) — rejected as insufficient.** It produces a
springy contact point, not a growing contact patch, correct pressure distribution, hysteresis,
or a load-dependent loaded radius. Retained explicitly as an *ablation* (fidelity level L1) to
demonstrate that rigid-contact simulation mis-ranks compliant wheels.

**Rigid hub + per-contact-point radial spring-damper (L2) — rejected as a primary model.**
Captures radial compliance and damping but not patch shape, spoke buckling, or lateral
coupling. Cheap fallback if the ring model proves unstable.

## Precedent

This is not novel in principle and should not be presented as such. The automotive tire field
solved it: **FTire** represents a full 3-D nonlinear tire with **80–200 lumped-mass nodes**
replacing the cord structure, running at **5–20× real-time**. Critically, flexible-ring tire
models have been **generated virtually from FEA rather than from physical measurement** —
exactly this project's situation, given no material test equipment.

The novelty is the application: closed-loop *dynamic obstacle traversal* at robot scale, with
the FEA step surrogated away to enable design *search*.

## Consequences

- The ROM is the project's central technical risk. Phase 1 gate (week 14) exists specifically
  to test it: ROM must reproduce FEA radial stiffness within 10% and Chrono dynamic ranking
  with ρ > 0.8.
- A dedicated batch FEA tier becomes mandatory (ADR-0005).
- Chrono becomes necessary as ground truth for validating the ROM (ADR-0004).
- **Ring discretisation `N` is a modelling parameter that can be exploited by the optimiser.**
  A discretisation sweep is therefore a required part of the solver-perturbation audit — a
  design whose score depends on `N` is an artifact, not a design.
- Every cache key must include the ROM version. Changing discretisation, fitting procedure or
  material homogenisation invalidates all prior results.
- The paper must state plainly what the ROM does *not* capture: high-frequency dynamics beyond
  the discretisation, large-strain nonlinearity outside the fitted range, local stress
  concentration, true post-buckling behaviour, progressive cyclic softening.

## Revisit if

- The Phase 1 gate fails. Fallback is family `T6` (soft tread on rigid hub), a far easier
  modelling problem, with correspondingly narrowed claims.
- A learned dynamics residual trained on FEA/Chrono rollouts outperforms the hand-designed
  ring model — this is extension 6 in `docs/plan/15-extensions.md` and would supersede this
  ADR rather than contradict it.

## References

- [FTire — physically based application-oriented tyre model](https://www.researchgate.net/publication/232851524_FTire_A_physically_based_application-oriented_tyre_model_for_use_with_detailed_MBS_and_finite-element_suspension_m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)
- [Virtual Generation of Flexible Ring Tire Models Using Finite Element Analysis](https://www.researchgate.net/publication/355688394_Virtual_Generation_of_Flexible_Ring_Tire_Models_Using_Finite_Element_Analysis_Application_to_Dynamic_Cleat_Simulat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)

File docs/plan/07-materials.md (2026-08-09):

# 07 — Material characterisation with no equipment

Literature values only. Workable, but must be planned around rather than ignored.

## What the literature gives you

- TPU is normally treated as isotropic hyperelastic, but **FDM introduces process-inherent
  anisotropy**, and raster angle clearly affects mechanical properties
  ([Prog. Addit. Manuf., 2024](https://link.springer.com/article/10.1007/s40964-024-00937-x)).
- On model choice: **neo-Hookean fits only the initial linear-elastic zone**, whereas
  **Ogden and Mooney-Rivlin approximate the whole stress–strain curve well**; a **third-order
  Mooney-Rivlin** model accurately described six different specimen groups across FDM
  process-parameter variations ([Polymers, 2025](https://doi.org/10.3390/polym17010026)).
- Infill pattern and density substantially change compression behaviour, studied
  comparatively for TPU across multiple patterns and densities.

**Starting point:** third-order Mooney-Rivlin, one parameter set per
(shore hardness × infill density × pattern), seeded from published fits, with orthotropy
introduced as a stiffness ratio between in-plane and interlayer directions.

## Cheap DIY characterisation — do this anyway

Under €100, and it pays for itself many times over:

| Test | Method | Yields |
|---|---|---|
| **Uniaxial tension** | ISO 37 / ASTM D638 dogbones; calibrated weights or a €20 digital luggage scale as load cell; elongation from photographs with fiducial marks | 10 load points → two- or three-term Mooney-Rivlin fit |
| **Compression** | Printed coupons, weights, dial indicator or calipers. One per infill pattern/density in use | Calibrates homogenised effective properties directly |
| **Damping** | Drop test or free-decay of a printed cantilever, 240 fps phone video; log-decrement | Damping ratio |
| **Hysteresis** | Load/unload a coupon in steps with 30 s holds; plot the loop | Loss factor |
| **Relaxation** | Fixed strain, photograph load reading over 10 min | One- or two-term Prony series |

One week of work. Turns "we used literature values" into "we used literature values verified
against in-house coupon tests," which is a materially stronger claim.

**What is still unavailable:** frequency-dependent viscoelasticity (needs DMA).
**Consequence: hysteretic rolling-resistance predictions will be qualitative, not
quantitative.** Scope claims to *ranking* rather than absolute values, and say so explicitly.

## Turn the limitation into RQ4

Rather than pretending to precision that isn't there, **randomise over material-model
uncertainty in the inner loop**: sample Mooney-Rivlin coefficients from a distribution
spanning published fits for that shore hardness, sample the anisotropy ratio, sample the
damping factor. Then:

- Score designs on **CVaR across material realisations** → designs robust to *not knowing the
  material*, which is what hardware transfer requires.
- Measure the **selection penalty**: how much worse is the design chosen under uncertainty
  than the design chosen with the true parameters (using a held-out "true" parameter set)?
  Clean, quantitative, publishable — and it converts an equipment gap into a contribution.

## The cyclic-softening problem — plan for it now

Under cyclic loading, TPU shows a **steep decline in absorbed energy over the initial
cycles**, after which the response becomes **increasingly dominated by viscous effects, with
continued softening rather than a stable plateau**. TPU's fatigue limit has been reported
around **10.25 MPa**, with cracks initiating at surface micropore aggregations and propagating
at ~45° ([Polymers, 2023](https://www.ncbi.nlm.nih.gov/pmc/articles/PMC9958809/)).

Three consequences:

1. **Hardware protocol must specify break-in.** Run every wheel for a fixed number of
   revolutions under nominal load before measurement. Otherwise trial 1 and trial 20 measure
   different wheels and the variance analysis is meaningless.
2. **Report measurements as a function of cycle count**, at least for one wheel, to quantify
   the drift. Genuinely useful to anyone building printed compliant wheels.
3. **Add a stress-margin constraint** on spoke root stress with a large safety factor, and log
   predicted cycles-to-failure as a reported (not optimised) metric.

**Practitioner caveat worth heeding:** TPU is excellent where parts should compress, cushion
or return softly, but is usually *not* the right material for a precise load-bearing spring.
Expect stiffness drift. Design for robustness to stiffness variation rather than for a
knife-edge optimum — which is what the RQ4 approach above already does.

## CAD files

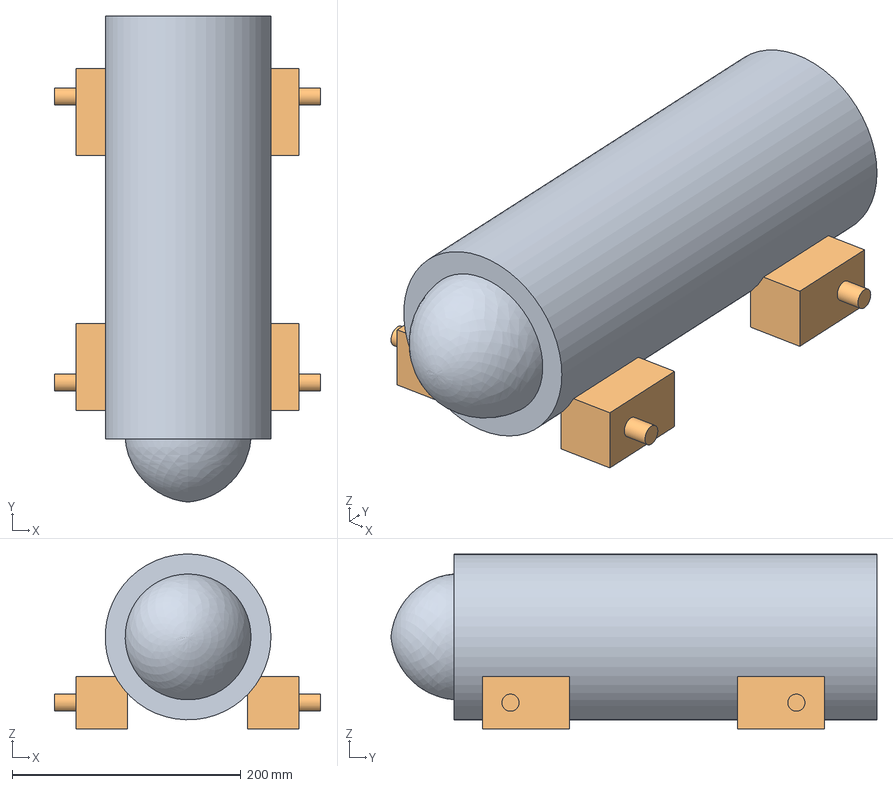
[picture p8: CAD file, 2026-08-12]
configs/pipebot_simplified.step
233.0 x 425.0 x 153.0 mm

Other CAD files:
configs/pipebot_simplified.stl

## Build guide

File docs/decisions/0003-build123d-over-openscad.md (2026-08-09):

# ADR-0003 — build123d for parametric CAD, not OpenSCAD

**Status:** accepted
**Date:** 2026-08-04

## Context

The project was originally conceived with OpenSCAD as the parametric CAD layer. The addition
of an FEA tier (ADR-0005) and multi-material TPU wheels changed the requirements on the
geometry kernel.

## Decision

Author all wheel geometry in **build123d**. Export **STEP** for FEA and archival, **STL** for
simulation collision and visuals. STL is never the source of truth.

## Rationale

1. **STEP export is mandatory.** The FEA solver needs BREP geometry. Meshing an STL for
   nonlinear hyperelastic analysis with contact is painful and produces low-quality elements.
   OpenSCAD (CGAL/Manifold, CSG) cannot produce STEP; build123d (OCCT) can.

2. **Region tagging for multi-material.** The FEA solver must be told which faces are TPU 95A
   at 40% gyroid infill and which are PETG. That requires named, queryable topological
   entities — a BREP concept, absent from CSG triangle output.

3. **Queryable topology makes manufacturability constraints checkable** rather than heuristic:
   overhang angles, minimum inter-spoke gaps, wall thickness. In OpenSCAD these would be
   inferred from triangle soup.

4. **In-process Python.** No subprocess round-trip, no file parsing, no stdout error handling,
   in a loop that will run thousands of times.

5. **OCCT over CGAL:** NURBS, splines, surface sewing, STL repair, STEP I/O; faster
   STL/STEP/3MF export than OpenSCAD.

## Alternatives considered

**OpenSCAD (original plan) — rejected.** Even with the Manifold backend (non-experimental
since late 2024, 5–30× faster than CGAL fast-csg, itself 30–150× faster than baseline Nef
routines) and SolidPython2 for programmatic generation, a **separate BREP path would still be
required for FEA**. Maintaining two geometry definitions of the same wheel is a reliable
source of silent divergence bugs.

**CadQuery — viable, not chosen.** Same OCCT kernel, same STEP capability. build123d replaces
CadQuery's fluent method-chaining API with stateful context managers, giving normal Python
control flow — loops, sorting, filtering over topology. For generating `N` spokes with varying
curvature under conditional parameters, that matters. They share the OCP wrapper, so objects
are interchangeable; switching later is cheap.

## Consequences

- ~3–5 days of migration cost if any OpenSCAD wheel definitions already exist.
- A build123d/OCCT dependency, which is heavier to install than OpenSCAD.
- Mass properties come from BREP volume directly, which is more accurate than mesh-volume
  integration and supports the invariant that mass and inertia are always derived, never
  hard-coded.
- The STEP output is directly usable for machining, external FEA, or handing to a
  collaborator — useful beyond this project.

## Revisit if

- A hard blocker appears in build123d that CadQuery does not share (switch is cheap — shared
  OCP wrapper).
- The project drops the FEA tier entirely, at which point OpenSCAD becomes viable again.

## References

- [build123d — external tools and libraries](https://build123d.readthedocs.io/en/latest/external.html)
- [CadQuery](https://github.com/cadquery/cadquery)
- [OpenSCAD Manifold backend no longer experimental](https://lists.openscad.org/empathy/thread/D6KV3ZLXHLBHSITSQ5GPUZUKHURU4ABE)

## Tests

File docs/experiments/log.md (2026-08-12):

# Experiment log

Append-only. Newest entries at the bottom.

**Write the entry — hypothesis and setup — *before* running.** Filling in the result
afterwards is what makes this a log rather than a changelog.

Claude has no memory of previous sessions. This file is the only record of what has been
tried, so an experiment that isn't logged here effectively didn't happen.

---

## Template

```markdown
## YYYY-MM-DD — <short title>

**Phase:** <0-5>
**Status:** planned | running | complete | abandoned
**Config:** <path or git hash>
**Run ID:** <id>

**Hypothesis.** What is expected and why.

**Setup.** What was run: designs, scenarios, seeds, budget, versions
(CAD / FEA / ROM / sim / optimiser).

**Result.** What actually happened. Numbers, not impressions.

**Interpretation.** What it means. What it rules in or out.

**Follow-up.** What to do next, or what this blocks/unblocks.
```

---

## 2026-08-04 — Project initialised

**Phase:** 0
**Status:** complete

**Setup.** Repository scaffolded. Plan split into `docs/plan/`, seven ADRs recorded in
`docs/decisions/` capturing decisions made during planning (simulator choice, ROM over FEM,
build123d, Chrono ground truth, CalculiX, multi-objective, CoACD).

**Result.** Documentation-only repo. No code, no experiments yet.

**Follow-up.** The one-week ROM feasibility spike in `docs/plan/16-first-week.md`. This is the
next action and it gates everything else — it tests whether an FEA-calibrated segmented-ring
model reproduces compliant-wheel behaviour well enough to optimise against.

---

## 2026-08-04 — CAD stage: compliant-spoke generator (first-week step 2)

**Phase:** 0
**Status:** complete, pending CAD-kernel verification
**Config:** `WheelParams` defaults — R=70, W=40, rim=3.0, hub=25, 16 spokes, t=2.0 mm,
kappa=0.004 /mm, CURVED, TPU_95A @ 40% infill, 3 walls

**Hypothesis.** A parametric `T3` compliant-spoke wheel can be generated, screened and
exported with mass properties derived from geometry, fast enough to sit in an optimisation
loop.

**Setup.** Six modules under `src/wheelopt/cad/`. Deliberate split: all geometry *maths*
(`centreline.py`) and mass properties (`massprops.py`) are pure numpy, so they are testable
without OCCT; `compliant_spoke.py` is a thin build123d adapter that only turns point arrays
into faces. 93 unit tests, all passing in 0.14 s.

**Result.**

- Mass properties validated against closed-form solids: box exact to 1e-12; cylinder polar
  and transverse moments to 4 decimal places at 2000 segments; annulus likewise. Scaling
  law `Izz ~ m R^2` confirmed (radius doubling gives 16.000x).
- Screening runs in well under 1 ms/design and never raises.
- **Two real bugs caught by tests, both silent-failure class:**
  1. `to_si()` converted `spoke_curvature_1_per_mm` as a *length* because the field name
     ends in `_mm` — curvature came out 10^6 times too small. Fixed by testing the
     `_1_per_mm` suffix first.
  2. `check_design` raised `ZeroDivisionError` on `n_spokes=0`, violating invariant 3.
     Geometry-dependent checks are now gated behind "no degenerate violations found".
- **One design error corrected:** the analytic inter-spoke gap estimate (arc pitch at the
  hub) was assumed permissive, but it over-reports the gap at low spoke counts and
  *under*-reports at high ones — so it silently rejected feasible designs above ~n=32.
  Removed entirely; the exact geometric check costs ~100 us, so the approximation bought
  nothing and created a second source of truth. Regression test guards its return.

**Interpretation.** The CAD stage is sound where it is tested. The build123d layer is
**unverified** — the development sandbox had no package-index access, so OCCT could not be
installed and no solid has ever actually been built. `scripts/verify_cad.py` exists to
close that gap: 25 checks covering solid validity, watertightness, tessellation
convergence, determinism, monotonic mass responses and export round-trip.

The two bugs found are worth noting as a pattern: both would have produced *plausible*
wrong numbers rather than crashes. That is the failure mode this project is most exposed
to, and it argues for keeping the pure-numpy/OCCT split as the pipeline grows.

**Follow-up.**

1. Run `python scripts/verify_cad.py` on a machine with build123d. Nothing downstream
   should be trusted until it passes.
2. Fill in `configs/robot.yaml` (first-week step 1) — `PlatformLimits` defaults are
   placeholders and a campaign run against them is not a valid campaign.
3. First-week step 3: CalculiX radial compression against a flat plate and a step edge.

---

<!-- New entries below this line -->

## 2026-08-05 — CAD stage executed against a real kernel for the first time

**Status:** complete. `scripts/verify_cad.py` exits 0, 37/37 checks.

**Hypothesis.** The build123d layer, written blind in a sandbox without OCCT, would either
fail outright on API misuse or work. Prior guesses at what would break — the `both=True`
extrude convention halving the width, the 16-spoke fuse returning a Compound rather than a
solid, the 16 × `make_face()` loop being slow or fragile — all turned out to be **wrong**.
The geometry code was correct as written. Everything that was actually broken was in the
*mesh extraction*, which nobody had reason to suspect.

**Config.** conda env `conda3.12`: Python 3.12.13, build123d 0.11.1, cadquery-ocp-novtk
7.9.3.1.1, numpy 2.5.1, CalculiX 2.23 (conda-forge, osx-arm64), gmsh 4.15.2. macOS arm64.
Nominal design unchanged: R=70, W=40, 16 spokes, t=2.0, kappa=0.004, CURVED, TPU_95A @ 40%.

**Result — the geometry is right.** Nominal wheel builds in 3.4 s. Single solid. Bounding
box exactly 140 × 140 × 40 mm, centred on z=0, so `both=True` does extrude `amount` in each
direction. BREP volume 182.87 cm³, mass 210.1 g. All three spoke profiles build; the tread
cutter — which had *no* coverage at all, since `tread_depth_mm` defaults to 0 — builds and
removes 11.2 cm³ without changing the envelope. Euler characteristic of the welded mesh is
V−E+F = 3416−10344+6896 = −32, i.e. **genus 17**: sixteen inter-spoke windows plus the
bore. The topology is exactly what the design intends.

**Three real defects, all in mesh extraction, all silent.**

1. **The tessellation was never watertight.** OCCT triangulates each BREP face
   independently, so vertices on a shared edge are emitted once per adjacent face: 63% of
   the 9332 raw vertices were duplicates and *not one edge* was shared. `is_watertight`
   was correct to reject it. Fixed with `export.weld_vertices()`, now called from
   `tessellate()`. Mass properties were unaffected (the divergence-theorem integral is
   per-triangle and never consults connectivity), which is exactly why this could sit
   undetected behind passing numbers.

2. **`tolerance_mm` did nothing.** build123d calls `BRepMesh_IncrementalMesh` with
   `isRelative=True`, so the linear deflection is scaled by feature size — on this geometry
   0.4 mm and 0.025 mm returned the *identical* 6896-triangle mesh. Compounding it,
   `Shape.mesh()` triangulates only "if none exists", and OCCT's boolean operations leave a
   triangulation behind at a deflection of their own choosing. The mesh being measured was
   a by-product of the union, not anything the caller asked for.

3. **STL export was order-dependent.** Same cause. The exported collision mesh varied with
   whether anything had tessellated the part earlier in the process, and at what tolerance:
   a fresh part gave 6896 triangles at every setting, but after a coarse `tessellate(0.4)`
   the same call gave 5608. Same design, different collision mesh, decided by call order —
   which would have quietly broken the Phase 0 determinism gate.

   Fixed by `export.remesh()`: clean the cached triangulation, then mesh with
   `isRelative=False`. Both `tessellate()` and `export()` now route through it. STL triangle
   counts are now identical regardless of call history and respond to the requested
   tolerance (5608 / 6896 / 12536 at 0.4 / 0.1 / 0.025).

**Consequence for tolerances: the angular tolerance dominates, not the chordal one.** The
volume error lives on the cylindrical surfaces, where facet count tracks angle. Refining
the chordal tolerance alone moves almost nothing; refining both together converges properly:

| tol (mm) / ang (rad) | triangles | volume (cm³) | error vs BREP |
|---|---|---|---|
| 0.4 / 0.4 | 5608 | 181.739 | −0.618% |
| 0.2 / 0.2 | 5944 | 182.502 | −0.201% |
| 0.1 / 0.1 | 6896 | 182.772 | −0.053% |
| 0.05 / 0.05 | 8736 | 182.850 | −0.010% |
| 0.025 / 0.025 | 12536 | 182.865 | −0.003% |

`verify_cad.py` section 8 now sweeps both and asserts the triangle count actually changes —
the old linear-only sweep produced a flat line and passed vacuously.

**One threshold changed deliberately, not patched.** `Izz/(m R²)` measured **0.434**,
just under the old 0.45 floor. This is not a bug: the T3 hub is a *solid* annulus from
r=3 mm to r=25 mm carrying ~42% of the volume close to the axle, which pulls the ratio below
the thin-disc value of 0.5. The bound is now 0.35–1.05, set from the geometry family rather
than the disc formula. If the hub is later webbed to save mass, expect this to rise.

**Interpretation.** The pure-numpy/OCCT split held up: 105 unit tests stayed green
throughout, and every defect was in the thin adapter, which is where the untestable logic
was deliberately concentrated. But the split also hid these — the adapter's *output* was
only ever checked for self-consistency (mesh vs BREP within 1%), and all three defects
preserved self-consistency while corrupting reproducibility. The lesson for the FEA stage:
check that a knob *does something* before trusting a study that varies it. A convergence
study that passes without the mesh changing is worse than no study.

**Follow-up.**

1. First-week step 3: CalculiX radial compression, flat plate and step edge. Environment is
   ready — `ccx -v` reports 2.23.
2. `configs/robot.yaml` still unfrozen; provisional values next, and nothing reads the file
   yet, so `PlatformLimits` remains authoritative in practice.
3. Consider a webbed hub. 210 g on a ~4 kg robot is 5.3% of chassis mass per wheel, and the
   solid hub is the largest single contributor while carrying almost no load.
4. The spoke-to-rim and spoke-to-hub junctions are sharp re-entrant corners. Harmless for
   mass properties, but they will produce mesh-dependent singular stress in FEA — a root
   fillet is likely needed before peak stress means anything.

## 2026-08-06 — CalculiX FEA driver stands up; five silent modelling bugs found

**Status:** complete. `scripts/verify_fea.py --full` passes 20/20 against CalculiX 2.23.
First-week step 3 is done.

**Hypothesis.** A STEP → gmsh → CalculiX → `k_r(δ)` pipeline could be built and made to
produce physically sensible radial-compression behaviour for a compliant wheel against both
a flat plate and a step edge. The interesting question was not whether the code would run —
it was how many of the modelling choices would be silently wrong, since FEA is exactly the
kind of stage where a plausible wrong number survives every check that isn't looking for it.
Answer: five, and every one was silent — no crash, no warning, a believable result.

**Config.** conda `conda3.12`; CalculiX 2.23 (conda-forge, osx-arm64), gmsh 4.15.2,
build123d 0.11.1. Verification design: R=40, W=20, 6 spokes, t=3.0 mm, TPU_95A @ 40%.
Second-order tets (C3D10), displacement-controlled, single `*STEP` sweeping 0 → 3× nominal
→ 0 via `*AMPLITUDE`. The `--tiny` model is ~53k DOF and solves in 2–4 min.

**The result is physics.** Flat-plate sweep: radial stiffness rises 0.9 → 1.3 kN/m
(stiffening, as a compliant wheel must), contact patch grows to 23×14 mm, loaded radius
falls monotonically, and the unloading branch retraces loading to within 1.3% enclosed area
— which is the right answer for a path-independent hyperelastic model. Step edge vs flat at
equal load: **smaller patch (65 vs 168 mm²) and higher peak pressure (1721 vs 1245 kPa)**,
which is the envelopment signature from `docs/plan/06`, §"Sanity checks". The single-element
patch test recovers σ = E·ε to a ratio of 0.99997, which validates the material card syntax,
the coefficient ordering, the SI unit system and the gmsh→Abaqus node ordering at once.

**Five silent bugs, in the order they bit.**

1. **`.dat` parsing dropped the entire load curve.** CalculiX uses *four* different
   leading-column conventions in one file — element output has two id columns (element +
   integration point), nodal output one, `TOTALS=ONLY` force output *zero*, and contact
   output names its id column. Worse, one block is headed `relative contact displacement`,
   and matching `displacement` before `contact` classified it as nodal displacement, where
   it overwrote the reference-node history and `build_load_curve` found nothing. Fixed by
   counting value columns from the header and taking them from the end of the row, and by
   matching contact blocks first. All four variants are now golden-file fixtures copied
   verbatim from real output (`tests/test_fea_parse.py::TestRealBlockVariants`).

2. **`*TIME POINTS` — the last set defined wins for everything.** CalculiX ignores the
   per-request `TIME POINTS=<name>`; a second, sparser set intended only for stress output
   silently thinned the whole load curve from 12 samples to 4. Measured directly (8-point +
   2-point sets → 2 output times for *both* displacement and stress). Now exactly one set.

3. **`D2 = 0` means infinitely stiff, not "off".** The volumetric energy is
   `Σ (1/D_k)(J-1)^{2k}`, so a zero higher-order coefficient is a *reciprocal* of zero.
   CalculiX substitutes ~1e-15 and warns quietly; the effect is 1/D2 ≈ 1e15 Pa and a
   volumetrically locked, far-too-stiff wheel. Fixed by setting D₂, D₃ large (negligible)
   rather than zero. This is the FEA cousin of the `_1_per_mm` bug from 2026-08-05: a
   natural-looking zero that means the opposite of what it reads as.

4. **Peak stress read at the wrong time.** The sweep ends *unloaded*, so reading the last
   stress block reports a wheel carrying nothing (~0 MPa) and every fatigue constraint
   passes. Now taken as the maximum over all sampled times.

5. **Loop area compared branches over different displacement ranges.** The loading and
   unloading branches are not sampled at the same displacements, so integrating each over
   its own range reported a 70% "hysteresis loop" for a curve that retraces perfectly. Now
   both branches are interpolated onto their common range; a retraced curve reports 0.

**Two more that would have killed a campaign, not just skewed it.**

6. **Non-deterministic meshing.** `Mesh.HighOrderOptimize = 2` gave the same STEP different
   node positions run to run (up to 0.13 mm) — which defeats the Phase-0 determinism gate
   and makes the cache key describe a mesh that was not the one solved — *and* intermittently
   aborted the process with an uncatchable C++ exception (`ScaledJac`), which invariant 4
   cannot defend against because it is not a Python exception. Disabled; the cost is slightly
   worse mid-side node placement, which is worth paying for a reproducible, non-fatal mesh.

7. **Curved quadratic tets folded and CalculiX rejected them at t=0.** gmsh curves C3D10
   mid-side nodes onto the bore and spoke fillets, folding elements whose straight-edge
   corner volume is still positive; CalculiX then reports `nonpositive jacobian determinant`
   and diverges before the first increment. Fixed with straight-sided quadratic elements
   (`Mesh.SecondOrderLinear`) plus a quadratic-Jacobian check (`_min_quadratic_jacobian`)
   that samples the shape-function determinant at corners, edge midpoints and centroid and
   raises a typed `MeshFailure` before the solver ever sees the mesh.

**Interpretation.** The pure/impure split paid off exactly as on the CAD stage: 265 unit
tests exercise deck text, parsing, extraction, the cache key and the failure paths without
gmsh or CalculiX installed, and every one of bugs 1–5 became a one-line regression test the
moment it was understood. But the split could not have *found* them — all five were only
visible when real solver output met real geometry, which is the argument for keeping a
`--full` verification tier that actually runs the binary. The recurring shape across this
stage and the CAD stage is a value that is zero, or a default, or a reused mesh, that reads
as innocuous and means something else entirely.

**Honest limitations, recorded so they are not rediscovered as bugs.**
- **No FEA hysteresis loss factor.** A hyperelastic model is path-independent; a real loss
  factor needs `*VISCO` + a Prony series, and `docs/plan/07-materials.md` says the Prony
  data needs DMA that is unavailable. `FeaResult.hysteresis_loss_factor` is `None` in
  `fea-0.1.0` by design, not omission. The 0 → 3× → 0 sweep is still run, as numerical QC
  and to detect buckling via a non-retracing unload.
- **Peak stress at the spoke root is mesh-dependent** (re-entrant corner singularity).
  `p95_von_mises_pa` is the mesh-convergent number a fatigue constraint should use; the raw
  peak is reported but should not be trusted until the CAD geometry gains a root fillet.
- **Hyperelastic coefficients are provisional seeds**, not coupon fits. Because the cache
  key hashes the coefficients themselves, replacing them invalidates prior results
  automatically.
- The material stiffness knock-down uses a Gibson-Ashby `φ^n` law, deliberately *not* the
  linear volume-fraction mix used for density — halving infill roughly halves mass but
  quarters stiffness. Documented in both places so the asymmetry is not "fixed" into a bug.

**Follow-up.**
1. First-week step 4: the 24–48-segment MuJoCo ring, joint stiffness fitted to this
   `k_r(δ)`. The FEA output contract (`LoadCurve`, `ContactPatch`, loaded radius) is what it
   consumes.
2. Add a spoke-root fillet to `cad/compliant_spoke.py` so peak stress becomes meaningful.
   Until then, gate the fatigue constraint on `p95` only.
3. Replace the provisional Mooney-Rivlin seeds with coupon fits per
   `docs/plan/07-materials.md` before any quantitative stiffness claim.
4. Run a mesh-convergence study once for the T3 family (`14-cad-toolchain.md`: once per
   topology family, not per design) to fix the production `MeshSpec`.

---

## 2026-08-07 — Bandless wheel (`T3b`): spoke tips as the running surface

**Phase:** 0
**Status:** complete. CAD and FEA both carry the variant; `verify_cad.py` 18/18 with the new
section 10, unit suite 297/297.
**Config:** conda `conda3.12`; build123d 0.11.1, gmsh 4.15.2, CalculiX 2.23.

**Hypothesis.** Removing the shear band (`rim_thickness_mm = 0`) is a small CAD change that
should make the *first* wheel easier to reason about: one spring in the load path instead of
two in series, so an FEA `k_r(δ)` is a statement about the spokes rather than about spokes
and band jointly. Expected cost: contact stops being axisymmetric. Expected surprise: at
least one place where the pipeline keeps working and quietly answers a different question —
that has been the pattern at every stage so far.

**Setup.** Nominal design R=70, W=40, 16 spokes t=2.0 for the CAD checks. FEA on the `--tiny`
preset (R=40, W=20, 6 spokes t=3.0, TPU_95A @ 40%), flat plate, δ_max = 4 mm, nominal 14 N,
compared like-for-like against the same preset with its usual 3 mm band.

**Result — the wheel is 4.6× stiffer, and then it buckles.**

| `--tiny`, flat plate, δ = 4 mm | banded (3 mm) | bandless, tip phase |
|---|---|---|
| Peak force | 3.78 N | **17.55 N** |
| Buckling | none | **limit point at 16.1 N** |
| Peak contact pressure | ~1.2 MPa | **18.0 MPa** |
| Contact patch length | 23.2 mm | ~0 (line contact, at the mesh's resolution limit) |
| Volume (nominal design) | 182.87 cm³ | 135.03 cm³ |

Not the direction guessed in advance. With a band, load spreads circumferentially and several
spokes bend; without one, the plate lands on a single tip and loads that spoke close to
**axially**, which is far stiffer than bending — until it Euler-buckles, which it does at
16.1 N, below 2.5× nominal, so `fea_buckling` fires as INFEASIBLE. The bandless wheel is not
a softer wheel; it is a strut that holds well and then lets go.

**Interpretation.** Worth keeping as the first article for exactly the reason it was asked
for — one identifiable spring — but it is a different mechanism, not a simplification of the
same one. `04-design-space.md` §`T3b` records the four consequences, of which the one that
matters for the week is that the ring ROM's segment-to-segment coupling *is* the band's
bending stiffness and is now zero: step 4 fits `N_s` independent radial legs, not a ring.

**Three silent defects, all of the house pattern.**

1. **The spoke tip sat outside its own outer radius.** The outline is offset perpendicular
   to the centreline, and a curved centreline is not radial at the tip, so the outboard
   shoulder rode past `outer_radius_mm` — 68 µm at the nominal design, **283 µm** at the
   corner of the design space (S-curve, κ = 0.03, t = 4 mm), and it is the shoulder rather
   than the corner that protrudes furthest. Fatal rather than cosmetic: the FEA tread node
   set is `|r − R| < 0.1 mm`, so the first material to touch the ground would not have been
   in the contact set at all. Invisible with a band, because the band was the running
   surface and the tips were buried inside it. Fixed by clipping the outline radially;
   `tests/test_bandless.py` sweeps profile × radius × curvature × thickness for it.

2. **`--tiny` silently overrode `--rim-thickness 0`.** `apply_tiny` assigned the preset
   unconditionally, so the flag was accepted and discarded, and the run reported the banded
   preset as the bandless design. `apply_tiny` now leaves alone anything the caller moved
   off its default, and prints what it kept.

3. **A load case that never touched the wheel reported `status: ok`.** Phased to the gap
   instead of the tip (−60° for six spokes), the plate descends into a void — the deepest
   material between two tips is 5.4 mm below the running surface, past the 4 mm sweep — and
   the solve converges in 50 increments with no cutbacks, no warning, and `k_r(δ)` identically
   zero. That reads downstream as an infinitely compliant wheel. Now a DEGENERATE
   `fea_no_contact` violation, and it is the *reason* `spoke_phase_deg` and
   `phase_for_tip_contact()` exist rather than a default of 0: with 6 spokes the default
   phase lands in the gap.

**Also changed.** `classify_nodes`/`classify_elements` put the tips in `spokes` rather than
`rim` when there is no band — otherwise the peak-stress output set excludes the highest-stress
elements in the wheel. The gmsh size field no longer applies the coarser rim size to the tips.
`draw_wheel_section` draws the running surface as a dashed circle, since there is no material
on it.

**Follow-up.**
1. Step 4 fits `N_s` legs, not a ring. Decide before fitting whether the ROM validation gate
   is still meaningful in that form, or whether the banded wheel has to be the gate design.
2. 18 MPa of contact pressure on a 3 mm tip is a durability question for printed TPU that
   simulation will not answer. Worth a printed part early.
3. The patch-length extractor reports ~0 mm for line contact. Honest, but resolution-limited
   — the tip carries only a couple of node rows at the `--tiny` mesh size. Re-check on a
   converged mesh before reading anything into it.
4. `k_r` is labelled "(stiffening)" even when both samples are negative, because the label
   compares peak against mid-sweep. Misleading on a post-buckling curve. Not touched here.

---
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

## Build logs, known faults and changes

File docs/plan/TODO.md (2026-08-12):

# Open work

The numbered list of what is not done. **IDs are stable and never reused** — a closed item
keeps its number so that a log entry or a commit message saying "closes #17" stays resolvable.

## What this file is, and is not

It is the *index* of open work. It says what is left, why, and what it depends on — one short
entry each, with a pointer to where the detail lives.

It is **not** a second record of what has been tried. That is `docs/experiments/log.md`,
which is append-only and is the only place a result should be written down. When an item here
closes, the evidence goes in the log and the entry here moves to the closed list at the bottom
with a date. If the two ever disagree, the log is right.

It is also not the plan. `docs/plan/11-phases.md` says what the project is doing over sixty
weeks; this file says what is blocking the next fortnight of it.

---

## Next

### #20 — Add tangential claw compliance to the ring ROM

**Done for the flat-plate and step rigs; open for what the number now rests on.** The
element, its MJCF realisation and the driven rig all work as of 2026-08-09 — see the log entry
of that date for the evidence and #27 in the closed table for the element itself.

Where it stands. A bandless ring's claws each have a root hinge with a moment-rotation law
measured by a `TIP_TANGENTIAL` sweep on the design's own claw sector, and
`scripts/run_step.py --tangential hinge` drives it. The R 60 mm, 12-claw, taper 0.6 design
passes **5/5 signatures** and clears a **60 mm step against the rigid wheel's 20 mm** at
matched mass, radius and rotational inertia. That is the project's first end-to-end claw climb
number, and it is **not** the spike's 50-vs-20, which was a banded `T3`. It read 30-vs-20 until
the #12 re-run; see the 2026-08-09 log entry, which supersedes that.

What is left, in order:

0. ~~The climb height is worth one significant figure and the sweep knows it.~~ **Done**
   2026-08-09: `step_climb_profile` keeps every outcome and `ClimbProfile` reports `censored`
   and `monotone`, so a climb is distinguishable from a bounce and from a sweep that ran out
   of range. The 10 mm resolution and the one-bucket sensitivity remain — quote a bucket.
1. ~~14% of loaded samples run past the fitted range.~~ **Done 2026-08-09, and the answer is
   negative.** Widening to 12 mm gets the step run to 0% beyond the fit and leaves the climb
   at 60 mm, but no fit of this design over its working range passes the 5% gate, and the
   12 mm fits cannot carry 24.5 N at all. The design load needs δ ≈ 8.2 mm against a 6 mm
   passing fit. Continued as **#29**.
2. **The step-edge patch disagrees between elements** — 24.0 mm for the hinge against 50.3 mm
   for the slide on the same design. That is the outward tip inflating the patch, so the hinge
   is the one to believe, but the size of the gap says patch length is the metric most exposed
   to the element choice and it is one of the five signatures.
3. **The hinge law is a rigid-bar idealisation of a bending claw.** It reproduces the measured
   tip trajectory to 2% mid-range and 13% at a full claw length
   (`fit.hinge_kinematics_check`), which is good enough to choose the element and not
   obviously good enough to quote a climb height to two figures.

Also unresolved and cheap: `run_step` graded a collapsed wheel **4/5** before this landed,
because it accepts any run whose history stays finite. `fraction_beyond_fit` did say 100%, but
the headline did not. The collapse is gone; the grading hole is not.

---

### #37 — The rigid family is the baseline and a candidate, and it cannot be built yet

Opened 2026-08-11 by the project review: the stated objective lets the optimiser pick **hard
plastic wheels**, and today the rigid side of the design space can express only a smooth
analytic cylinder in simulation — no `T0` in CAD, no `T1` grousers, no `T2` lobes, no
STL→CoACD→MJCF path for a shaped rigid wheel to collide with anything. As built, "a hard
wheel wins on this platform" is a conclusion the pipeline **cannot reach even if it is
true**, which biases the search by construction.

**Work, in dependency order.**
1. `T0` in CAD: a rigid cylinder with bore and (optionally) tread — a new topology switch,
   since `WheelParams` mandates spokes. Gives the hardware baseline a printable artefact and
   the sim baseline a mass/inertia derived from real geometry instead of the analytic ring.
2. `T1`/`T2`: grouser and lobe parameters (count, height, width / lobe count, depth), their
   screening (a grouser is an overhang; lobes change `polygon_drop`), and the CAD.
3. **CoACD→MJCF** (ADR-0007, promoted from #36): decompose the STL, enforce the hull and
   vertex budgets the ADR names, and mount the hulls on the rover's axles. This is the piece
   that lets a *shaped* rigid wheel collide.
4. Re-run the metric suite with `T1` in it — the first genuinely fair hard-vs-soft
   comparison this project will have produced.

~~Also carried here: re-derive `outer_radius_mm`'s bound from the wheel well.~~ **Done
2026-08-11 in the adoption commit**: bounds are (40, 90), floor from the horn seat, ceiling
by judgement with no pipe constraint — see the log entry of that date. What #37 still owns
is the rigid family itself (`T0`/`T1`/`T2` + CoACD) — noting that the interface is now the
**D53 horn**, so `T0`'s hub must seat it, and the small original wheels (r 22.5) are the
natural first `T0` print target for the bench-rig shakedown.

### #38 — Skid-steer scrub: the lateral gap, re-scoped and still open

Opened 2026-08-11 by the project review; the platform steers by scrubbing sideways and
"stability" is now an objective, so lateral behaviour stopped being deferrable by silence.

**The gap is narrower than the old docstrings said, and the narrowing is a closed form.** A
claw's out-of-plane stiffness is ``(w/t)²`` times its tangential one
(`WheelParams.lateral_stiffness_ratio`) — **~72x** on the R 60 family at the effective
thickness, 156x at the tip, and the taper only widens it (in-plane enters cubically, lateral
linearly). So the ROM's planar rigidity is a defensible *structural* approximation for wide
claws, and a skid-steer turn is chiefly a **friction** problem, which MuJoCo's Coulomb cone
models. What is actually unvalidated: (a) the ratio claim itself, against a 3-D FEA lateral
tip case (the 2-D tier cannot express it); (b) patch-level scrub of discrete tips — stick,
squirm and wear are not structure; (c) any design where ``w/t`` falls toward ~10.

**Work.** A 3-D `TIP_LATERAL` case on the claw sector to check the ``(w/t)²`` claim; a
differential-drive scenario in `sim/rover.py` (`WheelMount.side` already carries the sign)
measuring yaw rate and per-wheel scrub; and the hardware spin-in-place test from the
ADR-0008 protocol as the ground truth for the friction half. Turning results stay quarantined
until (a) passes.

**Decision 2026-08-11: spin-in-place is also S6's proxy.** The full figure-8/slalom path
track is deferred (recorded in `08-metrics.md`) — it needs #38's validation *and* a
path-following controller, and would measure the controller as much as the wheel. The spin
test answers S6's essential question (does this wheel let the robot turn, at what cost) as
one number per design; the full scenario returns only if designs differ meaningfully on it.

### #39 — Export a URDF from the platform spec (generated, never hand-written)

Opened 2026-08-11 from the ROS2 question. `robot.yaml` stays the source of truth — it holds
what URDF cannot say (print constraints, wheel envelope, operating point, provenance/frozen)
— and a `scripts/export_urdf.py` generates URDF from `PlatformSpec` + a chosen wheel, the
same way `build_rover_mjcf` generates MJCF. Hand-maintaining a second robot description is
the dual-source drift this repo keeps finding, so the generator is the only acceptable form.
Useful the day the robot runs ROS2 nav or someone wants RViz; nothing in the optimisation
loop needs it. USD/Isaac explicitly out (ADR-0001 rejected Isaac). Xacro only if the URDF
grows parameters worth templating — the generator IS the parameterisation, so likely never.

## The claw family's own gaps

These arrived with the `T7` redirection on 2026-08-08 and are listed in that log entry.

### #30 — Re-run the compliant-versus-rigid comparison on the rover, not the test rig

**Update 2026-08-11, after the platform adoption: the re-run happened and the ladder now
separates compliance — but not the element.** The measured platform de-saturated the sweep
(the old all-designs-clear-1.00R was the fictional robot's 1.19 m/s of momentum; the
measured 0.40 m/s robot's rigid cylinder clears **40 mm, 0.67 R**). On that ladder, at
matched mass/radius/inertia: the claw family clears **60 mm (1.00 R)** on radial slides —
the 6-claw inside its measured law (10.99 < 12.0 mm) — so **compliance buys +0.33 R on the
rover**, the first rover-level gap that survives the validity rules. Two things keep this
item open rather than closed: claw *count* still does not separate (6 and 12 tie; ranking
within the family stays with harshness/washboard), and the **element is worth the whole
gap** — the same 12-claw wheel reads 60 mm radial and 40 mm hinged (stalls at 50 grinding
303 J at 69% sharing). That 20 mm is #31's straddle expressed in ladder buckets; the
hardware step-edge test decides it. Log entry of the same date.

Opened 2026-08-10 by the four-wheel rigid rover, which climbs **three times** what the same
rigid wheel climbs on the single-wheel rig: 1.00 R against 0.33 R at R 60 mm, and 1.06-1.18 R
at R 85 mm. Nothing about the wheel changed; three other driven wheels push while one climbs.

**This puts a question mark over the headline ratio.** "Compliant clears 60 mm against the
rigid wheel's 20" is a single-wheel-rig number, and on that rig the rigid wheel is handicapped
by having no other wheels. If a rigid wheel recovers to 1.00 R on a robot, most of that 3x was
the rig rather than the compliance. The single-wheel result is not wrong — it measures what it
says — but it does not transfer, and the ratio must not be quoted as a property of compliance
until it has been measured on the rover.

**Work.** Put the fitted ring in the rover's four mounts (`ring_bodies(prefix=...)` is ready)
and re-run the comparison at matched mass, radius and rotational inertia, as the single-wheel
rig already does. Expect it to be slow: four rings is 4x the segment bodies and joints on a
timestep already tightened by the explicit-integration bound.

**And the metric it was going to be measured with does not discriminate.** 2026-08-10: on
`--sweep`, a 3-claw wheel, a 6-claw, a 12-claw and a plain rigid cylinder **all clear exactly
1.00 R** at R 60 mm. Four different wheels, one answer, in 10 mm buckets. So #30 needs a
metric before it needs a law — the flat-ground harshness of #33 does separate the same four
designs 4.5x, and cost of transport separates them 12x.

**Blocked on #31** for a law valid over what a rover does to a wheel — #29 closed by giving
the claw ring an exact law below second-claw engagement and showing that the element, not the
law, is what fails above it. Also blocked on the three gaps the rover's module docstring names,
of which the first is the serious one: the ring is **planar**, so a wheel loaded out of plane
-- by roll, or by dropping off an edge -- is perfectly rigid. A rover exercises that constantly
and the single-wheel rig never did.

### #31 — A claw at ±2π/n meets the plate on its flank, and the ring has no such contact

**Partly closed 2026-08-11, and the "measure before choosing" instruction has been carried
out.** See the log entry of that date. What changed:

- **The onset now has a closed form and it is right.** A claw's deepest material is its tip
  *corner*, half a thickness off its own axis, so its reach is `R cos θ + h sin|θ|`.
  `RingSpec.tip_half_thickness_m` (`rom-0.7.0`) puts that in both solvers. It predicts
  second-claw engagement at **7.14 mm** where the point tip said 8.04 and the FEA measures
  **7.20** — one sample. The 0.84 mm discrepancy this item opened with is explained.
- **It does not fix the straddle, and that is the finding.** Above engagement the error goes
  from +62.7% / −49.5% (slide / hinge) to **+74.7% / −45.6%**. The hinge gains 4 pp; the slide
  gets *worse*, because a too-late onset had been partly cancelling a too-stiff element. So
  contact onset was never the cause. **The cause is bedding** — a claw lying down along its
  flank, loaded in bending over a patch that travels — and no correction to a point-contact
  element reaches it.
- **The bound is now measured rather than asserted.** `BuiltRing.validity_delta_m` and
  `RoverResult.multi_contact_fraction` say where a ring is trustworthy and how much of a run
  left that range. Measured: a flat rover run at nominal load is on one claw for **91%** of
  the driving phase, so the ROM covers it; a 40 mm step run compresses one segment to
  **21.98 mm** against a law measured to 12, which is the *other* failure and is reported
  separately.

**What is left is one decision, and ADR-0008 (2026-08-11) changed its terms.** With printed
hardware as the ground truth, the multi-claw regime no longer needs an analytic flank-bedding
element to become trustworthy — it needs a **measured whole-wheel curve past second-claw
engagement from a printed wheel**, against which the ring's multi-claw response is calibrated
(the analytic element stays exact in the single-claw regime; above it, the printed curve is
the law). That path is: print the R 60 twelve-claw design, run the bench press protocol
(`docs/plan/17-hardware-baseline.md`), and fit. The analytic element (beam-on-foundation, or
a two-bar claw) remains the option if the calibrated ring still cannot track the *shape* of
the measured curve — build it then, against data, not before. Blocks a trustworthy `T7L`
(#35) and the rover step comparison (#30) either way.

Original statement follows.

Opened 2026-08-10 by #29, which set out to fix a fit and found that the fit was never the
problem. The log entry of that date carries both tables.

Below second-claw engagement a bandless claw ring built from one claw's own measured curve
reproduces the whole wheel to **0.036%**. Above it, the *same law* in the *same rig* gives
**+62.7%** with a radial slide and **−49.5%** with a root hinge, at δ = 9.6 mm on the R 60 mm,
12-claw, taper 0.6 design. Two idealisations bracketing the truth from opposite sides is a
statement about the **element**, not the law.

**What the element is missing.** The ROM loads every claw at its tip, along its own radius. A
claw 30° from the contact point meets a flat plate side-on, and carries load through its
*flank* — partly as a column, partly in bending, over a patch rather than at a point. Neither
a pure radial slide nor a pure root hinge is that. Independent evidence for the same thing,
from the onset rather than the magnitude: the FEA has a second claw carrying at **7.20 mm**,
0.84 mm *before* the geometric threshold `R(1 − cos 2π/n)` = 8.04 mm
(`ring.second_contact_delta_m`), because flank contact starts before the tip arrives.

This is the same gap CLAUDE.md's `T7` bullet already names — "a real claw beds onto its side
as it folds, and nothing here models that" — now with a number and a boundary. It is also the
same family as "the shear band does not shear": a correct discretisation of an incomplete
kinematic description.

**Work.** Decide what a segment's contact is. Options not yet costed: a capsule per claw whose
*side* is the collision surface with a compliance law along its length; a two-segment claw
(root hinge plus a mid hinge) so the flank can conform; or accepting the single-claw regime as
the ROM's validity envelope and screening designs on where their design load sits relative to
it. **Measure before choosing**, and note that the third option is nearly free and may be
enough — on this design the platform's 24.5 N per wheel sits at δ ≈ 1.1 mm, comfortably inside
the valid regime, and it is the *step* that leaves it.

**Blocks #30**, which needs a law valid over what a rover actually does to a wheel.

### ~~#29 — No fit of the driven claw design passes the gate over its working range~~

**Closed 2026-08-10, and it closed by refuting its own diagnosis.** See the log entry of that
date. Three things came out of it:

- **The sub-engagement failure was under-parameterisation, not ill-posedness.** Below
  `R(1 − cos 2π/n)` the whole wheel *is* one claw — measured to 0.036% — so there is no
  deconvolution over that range to be ill-posed. `fit_tabulated_law`'s default
  `n_intervals = min(8, len(d) // 2)` picks **3** intervals at 6 points, giving 10.42%, where
  **4** gives 1.71% and passes. Three cannot represent a curve that peaks at 2.4 mm.
- **Candidate 2 works and is now wired in.** `run_step.py --law claw` builds the ring from a
  claw-sector plate sweep with no fit in it, and spends the whole-wheel curve on
  `validate_ring` — a **held-out** check instead of training data.
- **The climb is 30 mm against the rigid wheel's 20**, not 60. The 60 came from `--law table`
  on a 6 mm fit; the exact measured law gives 30. Same design, same rig, same element: a 2×
  spread from the segment law alone.

What is left is not a fitting problem and has its own number: **#31**.

### #33 — Ride harshness is measured on flat ground only, where a rigid wheel cannot lose

**Closed in substance 2026-08-11; what remains is a sweep, not a build.** See the log entry.
`RoverSpec.washboard_amplitude_m` / `washboard_wavelength_m` and `run_rover.py --washboard
--wavelength` add S7's corrugation — a strip of boxes sampling the sinusoid, entered at a
trough so the doorstep is a ramp and the transient belongs to the terrain, not its edge.
**The sign reverses, and it is not close**: at 10 mm peak-to-trough the compliant twelve-claw
wheel beats the rigid cylinder **4.8–6.9x** at every wavelength from 60 to 400 mm, at equal or
higher speed, and the metric orders rigid > 3-claw > 12-claw the right way round. The caveat
travels with it: 20–53% of those runs have two claws sharing (the #31 element gap), so the
**sign** is the result and the second digit is not. Still open here: the amplitude x wavelength
*sweep* S7 specifies (this measured one amplitude), and terrain seeds over it.
**Amendment 2026-08-12: the amplitude × wavelength sweep is measured** — 3 × 4 grid on
the adopted platform, rigid/claw ratios 1.7–4.9x, compliant wins every cell at equal or
higher speed, and the claw wheel's harshness is nearly flat across the grid (its ride is
its own tip-passing, not the terrain). Log entry of that date. Remaining here: terrain
seeds over the grid, aggregated with CVaR (invariant 7).
**Amendment 2026-08-11 (adoption):** the "step climb cannot rank" premise softened — the
measured platform de-saturates the ladder (rigid 0.67 R, claws 1.00 R, see #30), so the step
sweep now separates compliant from rigid. What it still cannot do is rank *within* the claw
family, which remains this item's harshness/washboard job. Pre-adoption S7 ratios were
measured on the fictional platform and need re-measuring with the sweep.

Original statement follows.

Opened 2026-08-10 by wiring up objective 3. See the log entry of that date for the numbers.

`run_rover.py --obstacle-height 0` now measures RMS vertical chassis acceleration, and it
**does** rank wheels where step climb on the rover does not: 22.64 / 10.31 / 5.00 m/s² for 3 /
6 / 12 claws, against a single saturated 1.00 R for all of them plus the rigid cylinder on the
climb sweep. Two independent analytic companions — the closed-form polygon drop and the ring's
loaded ripple — track it.

**What is missing is the scenario where compliance wins rather than loses by less.** On a
smooth plane a smooth rigid cylinder reads 0.00 m/s² and cannot be beaten; every compliant
wheel is scored on how close it gets back to a wheel nobody can print. `08-metrics.md` asks S7
for a **washboard** — sinusoidal ripple swept over amplitude and wavelength — which is where
the sign is supposed to reverse, and nothing here demonstrates that it does.

**Work.** Add the S7 terrain to `sim/rover.py` (a strip of boxes, or a heightfield), sweep
amplitude and wavelength, and check whether a compliant wheel beats the rigid comparator at
any point in that space. If it does not, that is a result about the ROM's damping — every
cost-of-transport and harshness number is a statement about `TPU_LOSS_FACTOR = 0.15`, a
literature midpoint on a 0.05–0.30 span with no DMA behind it.

**Also open, smaller.** The metric is quoted at one speed, and harshness scales with speed;
`tip_frequency_hz` is reported alongside it so the two are not confused, but nothing sweeps
speed yet. And a wheel with few claws needs its segment law measured over its own polygon
drop — 30 mm for 3 tips at R 60 — which the FEA currently **cannot** reach: it diverges at 10
cutbacks by 20 mm. The `EXTRAPOLATED` warning is honest about it; widening 12 → 18 mm moved the
answer 8%, so the ranking is safe and the second digit is not.

### #35 — The L claw exists in CAD and cannot be simulated

Opened 2026-08-11 with the `T7L` topology itself. See `04-design-space.md` §`T7L`.

`tip_hook_mm` puts a tangential foot on the claw tip. The geometry is built, screened, drawn
and meshed — `verify_cad.py` is 60/60 with a new section 11, and the 2-D FEA tier solves a
12 mm foot on the R 60 twelve-claw design end to end. **What cannot be done with it is the
thing the wheel is for.**

The ring ROM loads each segment at a point along its own radius, through either a radial slide
or a root hinge. A foot's whole purpose is that it does *not* do that: it beds along an arc, and
the load moves along the foot as the wheel rolls. So `run_step.py --law claw` and
`run_rover.py --compliant` will build a ring for a `T7L` design and that ring will describe a
radial claw of the same length — silently, because nothing in the pipeline knows the difference.

This is **#31 arriving by design rather than by accident**, and it makes #31 harder to defer:
for `T7` the flank contact was an error above second-claw engagement, and for `T7L` it is the
first-order behaviour at any load.

**The refusal has landed.** `rom.build.build_ring` turns an L claw away by name, before any
solver time, and names this item in the message; `run_step.py --law claw` and `run_rover.py
--compliant` therefore stop rather than produce a number about a different wheel. Three tests
pin it, including that a footless design is still turned away for its *band* and not for a foot
it does not have.

**What is left is the element, and it is a decision before it is code.** Extend the segment so
a claw can carry a distributed contact — a capsule whose *side* is the collision surface is the
cheap version, and the rover already draws segments as capsules — or keep the refusal and treat
`T7L` as a CAD/FEA-only family. Measure before choosing.

Two smaller things travel with it, both easy to miss:

- **Nothing measures the sign.** A trailing foot folds closed under drive torque and a leading
  one is levered open; the field is signed, both are buildable, and no experiment separates them.
- **An early FEA observation, not yet a result.** At R 60, twelve claws, taper 0.6, plane
  strain: the 12 mm foot completes its sweep (90 increments, buckling limit point at 30.9 N)
  while the *plain* claw at the same settings **diverges**. One design each, so it is a note
  rather than a finding — but if it holds, a spread contact is easier on the contact solver as
  well as on the ride, and that would be worth knowing before choosing the element above.

### #34 — `rim_thickness_mm`'s lower bound is below the TPU wall, and unlike the spoke's, nothing says why

**Closed 2026-08-11: same rationale as the spoke, now stated for both, once, with the cost
measured.** The range must be able to express a design `rim_min_wall` rejects, or the check
can never fire — a constraint no sample can violate is indistinguishable from one that was
deleted. Cost: ≈5.9% of a uniform sweep per field, rejected in milliseconds by screening.
Shared statement in `04-design-space.md` §Manufacturing; both `PARAM_BOUNDS` comments point
at it. The trigger for revisiting is a real optimiser measurably concentrating near the wall,
and the remedy then is a material-dependent bound, not a raised floor.

Original statement follows.

Opened 2026-08-10 by `scripts/plot_geometry.py`, which draws each parameter across its own
range and puts the screening verdict under every panel. Two ranges come out red at their
searched lower bound. **One of the two is deliberate and documented; the other is not, and
that asymmetry is the item.**

`PARAM_BOUNDS["rim_thickness_mm"]` and `PARAM_BOUNDS["spoke_thickness_mm"]` are both
**(1.2, 8.0)** while `PlatformLimits.min_wall_thickness_tpu_mm` is **1.6** — 1.2 being the
*rigid* wall. Measured at R 60 with both fields set together: 1.2 and 1.5 each return two
`INFEASIBLE` violations, 2.0 is clean.

For the spoke this is on purpose. `params.py` says so in place: the bound sits below the wall
"so that `spoke_min_wall` stays a live check rather than being made unreachable by the range".
That is a real argument — a constraint no sample can violate is a constraint that has stopped
testing anything — and it is a trade against wasted evaluations, not an oversight.

`rim_thickness_mm` carries no such note. It may be the same reasoning applied twice, or it may
be the spoke's bound copied. **The work is to decide and write it down**, not to move a number:
either record the same rationale for the rim, or raise the rim's floor to the wall. If the
rationale is the right one it should also be stated once, in `04-design-space.md`, rather than
in a comment on one of the two fields.

**Worth measuring either way:** what fraction of a real search's samples land in the
unreachable band, which is the cost the rationale is being traded against. Nothing is searching
yet, so nobody has paid it.

The same figures show two bounds infeasible at the *top* — `n_spokes` 24 and 36 hit
`interspoke_gap`, `tread_depth_mm` 4 exceeds a 3 mm band. Those are honestly design-dependent:
they follow from radius, thickness and band, and a scalar bound cannot know them.

### #28 — The slenderness threshold of 40 is far too permissive for a claw

**Closed 2026-08-11: the threshold cannot be fixed, because the axis is flat where the
answer moves.** The frictional deep sweep this item asked for was run — claw sector, μ = 0.6,
12 mm, tapers 1.0 / 0.6 / 0.4 on the R 60 twelve-claw design — and **the stick branch has a
limit point**: 105.4 / 39.4 / 22.7 N at 2–4 mm of deflection. A 4.6× collapse in buckling
load, across which the slenderness proxy creeps **6.3 → 7.2 → 7.8**. No threshold on an axis
that flat ranks that family; tuning the 40 down to catch claws would be calibrating a constant
on three points of one family. The check that *does* catch them is `fea_buckling`, which
measures each design's own limit point against 2.5× nominal — it fails all three tapered claws
where the warning stays silent, and it already fired unprompted on the `T7L` run of the same
day. The warning is kept for the corner it was written for (a 1.6 mm strut on R 100 reads 48,
where geometry alone predicts a poor ROM fit) and its comment now states its blindness with
the measurement. Deeper than 12 mm the tapered claws diverge (~15–17 mm, 8–10 cutbacks) —
consistent with snap-back, which CalculiX has no arc-length solver to traverse; recorded as
the boundary of what this rig can measure.

Original statement follows.

Opened 2026-08-09 by #21, which fixed the *proxy* and left the *threshold*.

`constraints.py` warns above `slenderness > 40`. On the frictionless claw-sector plate sweep
of that date every design showed a load plateau — effective slenderness 8.1 through 26.0, so
none of them warns — and every plateau sat **below** the per-claw design load. A screening
threshold that fires on nothing in the family it is meant to screen is not screening.

**Do not simply lower it.** The frictionless plateau is the *slip* branch, and #24 established
that the physical branch is **stick**: at every μ from 0.2 to 1.2 the nominal claw carries
22.69 N at 1 mm against the frictionless 4.59 N, and the column mode does not appear there. So
the question is which branch a slenderness warning is about. Answering it needs a frictional
sweep deep enough to find the stick branch's own limit point, if it has one.

Until then the proxy is right and the threshold is decoration.

## Deferred

Real, understood, and not on the critical path.

### #36 — Phase 0's three unbuilt bullets: `T0` in CAD, CoACD→MJCF, Hydra

Recorded 2026-08-11, when the rest of Phase 0 closed (CI and the cross-machine gate — see the
log entry of that date). These three are the checklist items deliberately **not** built, each
because it currently has no consumer, and building for no consumer is how a wrong interface
gets frozen:

- **`T0` rigid cylinder in the CAD layer.** The *simulated* rigid baseline exists and is what
  every comparison uses — an analytic cylinder with matched mass, radius and inertia. The CAD
  `T0` is for printing a hardware baseline, which is Phase 4, and it does not fit
  `WheelParams` (spokes are mandatory there), so it is a new topology switch with its own
  screening — real surface area to add for a part nobody prints yet.
- **`STL → CoACD hulls → MJCF`** (ADR-0007). ~~Waits for the first `T1`~~ — **promoted into
  #37 on 2026-08-11**: the rigid family became a first-class candidate, so the first `T1` is
  now scheduled work rather than a hypothetical.
- **Hydra.** `configs/robot.yaml` is read by a tested loader and every CLI is argparse; the
  conventions section still names Hydra as the intended config system. Wiring it now churns
  eleven entry points for no behavioural change. The honest trigger is the optimiser (#9 in
  the plan), whose sweep configs are what Hydra is actually for.

What did close: CI runs the unit suite and lint on every push, and the **cross-machine
determinism gate is now a live experiment** — three designs' S1 ladders, run on Linux x86-64
against manifests committed from this macOS arm64 machine, bit-for-bit. `run_s1.py
--manifest-out/--manifest`, `store.manifest_from_records`/`compare_manifests`.

### #32 — `fit_tabulated_law`'s default interval count is a rule of thumb, and it is too coarse

Opened 2026-08-10 by #29, which found it while looking for something else.

`n_intervals = min(8, len(d) // 2)`. On six points that is **3**, and on the one case where
the exact answer is known — a bandless claw wheel below second-claw engagement, where the whole
wheel is a single measured curve — 3 intervals give **10.42%** RMS where 4 give **1.71%** and
pass the gate. Three cannot represent a curve that peaks at 2.4 mm and softens for the next
ten; the halving is not derived from anything about the curve.

**Deferred rather than fixed, because changing it moves every number this project has.** Every
banded fit on record was taken at the current default, and the honest way to change it is to
re-fit and re-measure rather than to raise a constant. The bandless claw path no longer needs
it at all (#29), which is why this is not urgent.

**Candidates.** Choose the count by cross-validation on the curve rather than from its length;
or keep the rule and raise the floor; or expose it and make every caller state one. The
`smoothing` penalty already there is the reason a finer table is not automatically worse.

**2026-08-11: the first candidate is built, opt-in, and the default is untouched.**
`fit.n_intervals_by_cv` picks the resolution by leave-one-out prediction — the number that
turns back up where fit error keeps falling — and on a curve generated from a known 4-interval
law it recovers **4** where the length rule picks 3; ties go to the coarser table, endpoints
are never dropped (the fit does not claim its own extrapolation), and a caller passes the
result explicitly as `n_intervals=`. What keeps this item open is unchanged: *switching the
default* to it means re-fitting every banded result on record, and that re-run has not been
done. The tool now exists for the day it is.

---

## Standing gaps

Not tasks with an owner or a next action, but things a reader should know are missing. Each is
argued where it lives; they are collected here so the list of what is *not* modelled is in one
place.

- **The shear band does not shear.** Bending and hoop only, so contact patch length from the
  ROM is a lower bound. `src/wheelopt/rom/ring.py` module docstring.
- **No hysteresis from FEA.** Hyperelasticity is path-independent; a loss factor needs
  `*VISCO` plus a Prony series, which needs DMA data this project does not have. Damping is a
  material parameter, `sim.step_climb.TPU_LOSS_FACTOR = 0.15`, a literature midpoint on a
  0.05–0.30 span. Every cost-of-transport number is a statement about that constant.
- **`configs/robot.yaml` is not frozen.** `meta.frozen: false`. The chassis envelope is a
  requirement; mass, motors, battery and inertia are estimates.
- **`MeshSpec.half_width_symmetry` is declared and not implemented**, and `__post_init__`
  refuses `True` rather than accepting it silently. See the field's comment.
- **No anisotropy.** CalculiX has no anisotropic hyperelastic model, and an FDM part is
  layered. Out of scope, not overlooked.
- **The ring is planar; a robot is not.** Each ring lies in its own x-z plane and its segments
  move radially and in-plane-tangentially only. A wheel loaded **out of plane** — by chassis
  roll, or by dropping off an edge — is perfectly rigid in this ROM. The single-wheel rig never
  exercised it; `wheelopt.sim.rover` does, constantly. Same family as "the band does not shear".
- **Skid steer scrubs, and that is not validated.** Four non-steered wheels cannot turn without
  sliding sideways, and lateral scrub of a segmented capsule ring has never been compared
  against anything. Only straight-line driving is supplied.
- **Phase 0 is part done, as of 2026-08-10.** Landed: the store (`wheelopt.store`, append-only
  Parquet + DuckDB), the metrics layer (`metrics.aggregate` CVaR-25%, `metrics.threshold` the
  logistic P=0.9 height), and **scenario S1 end to end** (`sim.s1_step`, `scripts/run_s1.py`) —
  80 runs in 23 s giving 44.7 ± 9.1 mm on rigid R 85 wheels. The determinism gate runs and
  passes **on one machine**: 80 repeated `run_id`s, zero disagreements.
  Still open: `T0` in the CAD layer, CoACD→MJCF, Hydra wiring, CI on three designs under five
  minutes, and the gate's actual claim — *two machines, two days apart*, which nothing has
  tested. `docs/plan/11-phases.md`.

---

## Closed

Kept so the numbering stays unambiguous. The evidence for each is in
`docs/experiments/log.md` under the date given.

| # | Item | Log entry |
|---|---|---|
| 1 | Set up the `conda3.12` environment | 2026-08-05 — CAD stage executed against a real kernel |
| 2 | Verify and fix the CAD stage against a real kernel | 2026-08-05 — same entry |
| 3 | Build the CalculiX FEA driver (first-week step 3) | 2026-08-06 — driver stands up; five silent bugs |
| 4 | Fill `configs/robot.yaml` with provisional values | 2026-08-07 — the platform was wrong |
| 5 | Re-run FEA sweeps at the re-specified platform; update `04-design-space` §`T3b` | 2026-08-07 — re-measuring at the new platform |
| 6 | Make `configs/robot.yaml` authoritative: loader plus agreement tests | 2026-08-07 — same entry |
| 7 | Decide how the nominal design gets an FEA evaluation at ~20 h/sweep | 2026-08-07 — same entry |
| 8 | Build the 2-D plane-strain FEA tier | 2026-08-08 — the 2-D tier works |
| 9 | Try the one-element-thick 3-D slab as the cheap tier | **no entry — see below** |
| 10 | Make the 2-D tier handle friction, or refuse it | 2026-08-08 — the 2-D tier works |
| 11 | Calibrate the 2-D tier on more than one design | 2026-08-08 — calibration across topologies |
| 13 | First-week step 4: the segmented-ring ROM fitted to `k_r(δ)` | 2026-08-08 — same entry |
| 14 | Add neighbour coupling to the ring, and re-fit | 2026-08-08 — the shear band |
| 15 | First-week steps 5–6: drive the ring at a 50 mm step and judge it | 2026-08-08 — steps 5 and 6 |
| 16 | Replace the cubic spring law with a tabulated one | 2026-08-08 — it was never the cubic |
| 17 | Make `detect_buckling` test a magnitude, not a sign | 2026-08-08 — same entry |
| 18 | Per-claw FEA sector, and a ROM whose segments are the claws | 2026-08-08 — segments are claws |
| 25 | `scripts/explore.py`, the manual playground and its HTML report | 2026-08-08 — a manual playground |
| 24 | Separate tip slip from structural response in the claw curve | 2026-08-08 — stick or slip |
| 26 | Settle how the ring resolves a frictionless contact force | 2026-08-09 — MuJoCo settles #26 |
| 27 | Replace the ring's tangential slide with a hinge at the claw root | 2026-08-09 — the root hinge, and the damper |
| 19 | Re-derive the `n_spokes` lower bound for claws | 2026-08-09 — the claw family's two screening gaps |
| 21 | Fix the slenderness proxy for tapered claws | 2026-08-09 — same entry |
| 23 | Drive a softening spring law in MuJoCo deliberately | 2026-08-09 — a softening segment, uneventful |
| 22 | Fix the coupled tabulated fit, which stalls | 2026-08-09 — #22 and #12: two deferred items |
| 12 | Reconsider the default `contact_stiffness_factor` of 20 | 2026-08-09 — same entry |
| 29 | No fit of the driven claw design passes the gate | 2026-08-10 — the law was never the problem |

Several of these closed differently from how their titles read, which is worth knowing before
trusting one:

- **#9 was never run and has no log entry.** It existed only as a workaround for a supposed
  plane-strain limitation that turned out not to exist, so #8 superseded it. C3D15 node
  ordering *was* validated along the way — counter-clockwise bottom triangle gives exactly the
  closed-form `E·ε·A`, flipped gives a nonpositive Jacobian — so the slab is still available
  if the 2-D tier's frictionless restriction ever needs lifting.
- **#16 was titled "tabulated *monotone* law"** and closed by establishing that monotonicity
  was the thing to remove.
- **#19 closed by moving the bound the other way.** It expected to widen `n_spokes` downward
  for claws and the measurement said a passive claw wheel wants **more** tips, not fewer —
  twelve, against the six already in the bounds. `PARAM_BOUNDS` is therefore unchanged and the
  claw-specific limit is a warning that fires only without a band.
- **#21 fixed the proxy and left the threshold**, which is now #28.
- **#22 was a cost fault, not an accuracy one.** The projection *was* the culprit, exactly as
  its suspect list said, and the free-block step cut it from 400 iterations and 4004 residual
  evaluations to **4 and 37** with an honest `converged=True`. But the error moved 14.55% →
  **14.54%**. The 8.32% it was framed against belongs to a *bandless* fit, which is a different
  problem, not the same one solved better. The other two suspects — finite-difference noise and
  too many parameters — are refuted.
- **#12 changed two things, and the second was not the one it was filed for.** The default
  factor moved 20 → 5 as expected (0.7–0.8% of the answer on the 3-D tier, 3 cutbacks to 0).
  The cap it asked about "for consideration" turned out to be **load-bearing**: the factor
  alone cannot make a fine mesh converge — at 2.5 and 1.5 mm both 20 and 5 diverge — and it is
  the absolute penalty that decides, so `contact_length_floor_m` is a fix and not a tidy-up.
- **#23 closed by not reproducing.** It was filed expecting dynamic snap-through and energy
  growth; a softening segment runs cleanly at every severity tested, because the payload is a
  dead weight rather than a prescribed displacement and there is always a branch to land on.
  What it *did* find is that the loss-factor damping has no defined stiffness to read on a
  softening branch, worth ~8% of cost of transport, and that its own proposed remedy — the
  minimum tangent — is negative and would inject energy.
- **#27 was right about the element and wrong about what it would fix.** The hinge is the
  correct element and the FEA says so directly — the claw's tip comes *inward* as it bends,
  by +19.7 mm measured against the hinge's +22.6 mm prediction and the slide's −13.9 mm. But
  the driven wheel's collapse was **not** the slide's kinematics. It was the loss-factor
  damping, integrated explicitly, on a joint whose effective inertia is 120x below the segment
  mass it had been scaled by. Moving the same damping into the joints' native `damping`
  attribute fixed it, and the *slide* rig runs now too.
- **#25 found a bug in its first hour that no existing test could see.** The rigid
  comparator's inertia sat exactly on MuJoCo's triangle-inequality boundary, so whether the
  model loaded depended on decimal rounding — rejected in 3 of 54 geometries, and never on
  `--tiny`. That is the case for building the tool before more physics, and it made it
  itself.
- **#18 closed with its machinery working and its purpose blocked.** The claw sector meshes
  and solves — 492 elements against 3155, 0.2 s against 41.7 s, agreeing with the whole wheel
  to 0.07% — and `ring_from_claw_curve` builds a ring from the curve with no fit in it. But
  the curve was not yet a spring law. **#24 closed that**: the radial curve is well determined
  on the stick branch, insensitive to friction above mu=0.2 and mesh-converged to under 1%.
- **#4 and #6 both concern `configs/robot.yaml` and neither froze it.** `meta.frozen` is
  still `false`; see the standing gaps above.
- **#29 closed by refuting its own diagnosis, and it moved the headline.** It was filed as
  ill-posed deconvolution on a bandless wheel; below second-claw engagement there is no
  deconvolution at all, because the whole wheel is one claw to 0.036%. The real cause of the
  sub-engagement failure was a default of 3 table intervals where 4 passes. And the claw
  design's climb is **30 mm against the rigid wheel's 20**, not the 60 recorded on 2026-08-09
  — the difference is the segment law, and nothing else. Continued as #31.
- **#26 closed against the incumbent, and the correction is small on today's designs.**
  MuJoCo matched `f_r/cos θ` to 6e-11 and `f_r·cos θ` to 25%, so the ring was wrong — but the
  tiny design's fitted `a` moves only 3.6% at 24 segments and under 0.3% at 36 and 48, because
  its patch is three segments wide. The correction scales with how far the patch spreads
  (14.1% at ±30°), so it matters for claws and barely at all for `T3`. Do not cite it as a
  reason previous `T3` numbers were wrong.

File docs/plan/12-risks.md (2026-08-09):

# 12 — Risk register

| # | Risk | Likelihood | Impact | Mitigation |
|---|---|---|---|---|
| **R1** | **ROM fails to reproduce FEA/Chrono behaviour adequately** | Medium | **Critical** | Phase 1 gate at week 14; fallback is `T6` (soft tread on rigid hub), far easier to model, with narrowed claims |
| R2 | Optimiser exploits contact-solver or ring-discretisation artifacts | **High** | Critical | Solver-perturbation audit incl. discretisation sweep, cross-engine gate, complexity regulariser |
| R3 | FEA pipeline unreliable in batch (convergence failures on soft, buckling geometry) | **High** | High | Robust restart/relaxation schemes; non-convergence is a typed infeasibility, never a crash; log convergence rate as pipeline health |
| R4 | Material model wrong → designs don't transfer | **High** | High | DIY coupon tests; material randomisation; measure real stiffness in Phase 4 and recalibrate |
| R5 | Insufficient throughput | **High — realised** | High | ROM surrogate removes FEA from the loop; T0 pre-filter; aggressive caching; ring segment count tuned to the minimum passing the discretisation audit. **Measured 2026-08-07: the nominal design costs ~20 h per 3-D sweep**, not the 10–40 min this row assumed — 279 k DOF at ~23 min per increment, and coarsening does not help because the band, spoke and bore set the element size. Mitigated 2026-08-08 by the 2-D plane-strain screening tier (20 k DOF, 7.5× less solver time, `k_r` within 14% of 3-D), with 3-D kept as the reference for a small number of designs. See `docs/experiments/log.md` |
| R6 | Insufficient novelty vs NPT literature | Medium | High | Position explicitly against the NPT corpus; lead with C1 (dynamic closed-loop ROM search) and C3 (obstacle traversal at robot scale), not "we optimised spokes" |
| R7 | TPU stiffness drift invalidates hardware measurements | **High** | Medium | Break-in protocol; periodic re-measurement; report drift as a result |
| R8 | Compliant designs buckle or fatigue-fail in testing | Medium | Medium | Buckling and stress constraints with large safety factors; print a spare of each; treat failures as data |
| R9 | Controller confound | Medium | High | Joint controller optimisation from Phase 2; sequential-vs-simultaneous ablation |
| R10 | Rig repeatability worse than the effect size | Medium | High | Pilot the rig with the stock wheel and measure trial-to-trial variance *before* printing candidates; size the expected design gap against it |
| R11 | Scope creep into deformable terrain | **High** | High | Hard rule: no deformable terrain before Phase 3, and then only at T2b fidelity |
| R12 | Multi-objective results hard to communicate | Medium | Low | Three named preference profiles (obstacle-first, efficiency-first, balanced); one champion each |

## Review cadence

Revisit this register at each phase gate. Add new risks as discovered; mark retired risks as
retired rather than deleting them — knowing which risks did *not* materialise is useful when
writing up.

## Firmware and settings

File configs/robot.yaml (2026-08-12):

# Robot platform specification — THE FROZEN SPEC
#
# Everything downstream depends on this file. Phase 0, step 1 is to fill it in and stop
# changing it. If it changes later, every cached result is invalid.
#
# Units: SI throughout (m, kg, s, N, N·m, rad). No millimetres in this file.
#
# STATUS: PROVISIONAL — the *chassis envelope* is a real requirement (400 x 300 x 200 mm,
# given 2026-08-07); everything else is derived to be self-consistent with it and is NOT
# measured. `frozen` stays false: a campaign run against these numbers is a pipeline test,
# not a result. Every value carries its provenance below.
#
# HISTORY: 2026-08-07 the platform was re-specified from a ~4 kg, 300 x 220 x 120 mm class
# robot on 70 mm wheels to the 10 kg, 400 x 300 x 200 mm four-wheel rover below. Nominal
# wheel load went 14.0 -> 24.5 N, which moved the whole wheel design space; see
# docs/experiments/log.md 2026-08-07 for what that invalidated.
#
# NOTE: nothing in the codebase reads this file yet. `PlatformLimits` in
# src/wheelopt/cad/constraints.py duplicates a subset of it and is what actually
# constrains screening today — but as of this revision the two agree, so the duplication is
# no longer also a contradiction. Wiring the loader is what first-week step 1 really is.

meta:
  name: piperobot-426x231           # the measured pipe robot (configs/pipebot_detailed.stl)
  frozen: false                     # pipeline should refuse to run a campaign while false
  frozen_date: null
  provenance: >
    Chassis footprint and height are a stated platform requirement. Mass, drivetrain
    layout and driving direction were chosen 2026-08-07: 10 kg all-up, four-wheel skid
    steer, 400 mm in the driving direction. Everything below is derived from those four
    facts to be mutually consistent. Motors, battery and inertia are class-typical
    estimates, not measurements.

# =========================================================================================
# MEASURED FROM THE 3D MODEL, 2026-08-11 (configs/pipebot_detailed.stl, units mm, 156k tris;
# the model's own mid-body clearance of 34 mm cross-checks the hand-measured 3 cm):
#   overall               426 x 231 x 187 mm  (length x width x height, wheels included)
#   wheelbase             250 mm     (stated value below: 260 -- close, PENDING adoption)
#   track                 157 mm     (stated value below: 350 -- FICTION, PENDING adoption)
#   existing wheels       r ~22.5 mm, four contact patches confirmed on the floor plane
#   structure at r 26.5 from every axle -- consistent with the MX-64 servo horn (D53), which
#     ROTATES with the wheel and therefore caps nothing; the true wheel-radius ceiling is an
#     APPLICATION question (the circular ~187 mm shell says pipe-fit) the STL cannot answer.
# ADOPTED 2026-08-11 after the user answered the gating questions: no pipe-fit constraint,
# the r-26.5 structure is the servo HORN (rotates, caps nothing), wheel width is free
# outboard, and the 8.5 kg was ready-to-run (~8.0 without wheels). This commit is the
# deliberate cache-invalidating adoption the pending block promised.
# =========================================================================================
chassis:
  mass: 8.0                         # kg, EXCLUDING wheels. MEASURED 2026-08-11 (user):
                                    #   8.5 kg ready-to-run with batteries, motors and the
                                    #   original wheels; ~8.0 without wheels. Conservative
                                    #   estimate by the user's own statement.
  length: 0.426                     # m. MEASURED off the 3D model (STL bbox, cross-checked
  width: 0.231                      #   by the hand-measured clearance). The body is a
  height: 0.157                     #   circular ~187 mm shell; the box is its envelope
                                    #   above the belly line (187 - 30 clearance = 157),
                                    #   which is what the belly-contact geom needs.
  com_offset: [0.0, 0.0, 0.0]       # m, assumed geometric centre until measured
  inertia: [0.0512, 0.1374, 0.1566] # kg·m², uniform-box formula at 8.0 kg on the measured
                                    #   dims (estimate; the real one needs component masses
                                    #   in the 3D model -- 17-hardware-baseline.md)
  ground_clearance_min: 0.030       # m. MEASURED 2026-08-11, twice: by hand (3 cm) and off
                                    #   the STL (34 mm lowest mid-body) -- AT THE ORIGINAL
                                    #   r 22.5 mm WHEELS. Clearance is wheel-dependent:
                                    #   see axle_to_belly below, which is the invariant.
                                    #   Old note: the
                                    #   axles sit near the bottom of the chassis.
  axle_to_belly: 0.0075             # m, belly height ABOVE the axle line: 0.030 clearance
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

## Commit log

2026-08-09 Tangential claw compliance in the ROM, and fix how the ring resolves contact force Two pieces, the second found while building the first. FEA cases TIP_RADIAL / TIP_TANGENTIAL measure a claw's two st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
2026-08-09 MJCF tangential joint, and the finding that it needs to be a hinge
    Adds the tangential freedom to the MuJoCo ring (opt-in, refused on banded
    specs, validated per segment against solve_equilibrium_2dof to 1e-9 in the
    static press), plus stable_timestep_s: qfrc_applied is integrated explicitly,
    so a stiff segment law needs omega*h <= 0.2. The radial-only rig had been
    running at 0.63 and surviving by luck.
    --tangential now measures the law by a TIP_TANGENTIAL sweep on the design's
    own claw sector and tabulates it (law_from_claw_curve) instead of taking a
    stiffness: the claw stiffens 3.6x in secant and 13x in tangent by one claw
    length, so a single k_t is only its first 10 mm.
    Filed #27. The d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
2026-08-09 Root hinge for the claw ring, and the last five open TODO items #27 replaces the ring's tangential slide with a hinge at the claw root. The FEA settles it from outside the model: with the tread's rad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
2026-08-10 added a rendered for the spoke wheels in mujoco
2026-08-10 Close #29, and the claw climb drops from 60 mm to 30
    The whole robot, and a segment law that is measured rather than fitted.
    `wheelopt.sim.rover`: a free-jointed chassis box with configs/robot.yaml's own
    mass, inertia, wheelbase, track and motor curve, on four driven axles. A rigid
    wheel climbs 1.00 R on it against 0.33 R on the single-wheel rig -- three other
    wheels push while one climbs -- so the spike's rig ratio may be mostly the rig.
    Filed as #30. The platform loader now reads the seven vehicle fields that sat
    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
2026-08-11 Phase 0 infrastructure, a metric that ranks wheels, and the L claw
    The rover's step-climb sweep cannot tell wheels apart: 3 claws, 6, 12 and a
    plain rigid cylinder all clear exactly 1.00 R. Flat ground can — obstacle
    height 0 is now a scenario, not a degenerate step, and reports RMS vertical
    chassis acceleration: 22.6 / 10.3 / 5.0 / 0.0 m/s2 for the same four wheels,
    with axle work separating them 12x. Two checks from outside the sim track it,
    the closed-form polygon drop and the ring's loaded ripple. Few-clawed numbers
    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
    [robot.yaml]
2026-08-11 Phase 0 closes: cross-machine gate in CI, S7 washboard, #31 measured to its boundary, and the L claw
    The washboard is where the sign reverses: compliant beats rigid 4.8-6.9x on
    harshness at every wavelength, at equal speed, where flat ground scored it
    against an unbeatable 0.00. #31's onset now has a closed form (tip corner,
    7.14 mm predicted vs 7.20 FEA) and the straddle survives it — the cause is
    flank bedding, which no point element reaches; every compliant run now prints
    how much of it left the validated regime. T7L adds an L-shaped claw the CAD,
    screening and 2-D FEA take and the ROM refuses by name (#35). CI runs the unit
    suite and re-runs three S1 ladders bit-for-bit against committ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
2026-08-11 The robot arrives: adopt the measured platform, and clearance becomes wheel-dependent
    The pending block in robot.yaml is resolved — the project now describes the machine
    that exists, not the estimated one. Four Dynamixel MX-64AT (6.0 N·m, 6.6 rad/s at the
    output), 8.0 kg chassis ex-wheels, 426×231×157 mined from configs/robot_piperobot.stl,
    wheelbase 250 / track 157, D53 servo-horn mount, 20.6 N per wheel, radius bounds
    (40, 90). LoadCase.nominal_load_n moves 24.5 → 20.6, deliberately invalidating the
    FEA cache — the old corpus described a fictional robot.
    The belly rides a fixed 7.5 mm above the axle line, so clearance = R + 7.5 mm
    (PlatformSpec.ground_clearance_for) instead of a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
    [robot.yaml]
2026-08-12 The rover wears its own shell: external wheels, wheel-dependent track, and a chassis of primitives
    The user split the model: configs/pipebot_detailed.stl (the measurement reference,
    renamed) and pipebot_simplified.stl/.step, purpose-built for the sim. The shell is
    drawn by default over the contact box, registered by its axle stubs — stations give
    wheelbase 250.03 against the platform's 250, and stub height matches the detailed
    model's measured axle line to 0.07 mm. Decoration contract pinned: zero mass, zero
    collision, byte-identical numbers, and a test maps the real STL through the compiled
    geom pose onto the sim's axles.
    The stubs settled where candidate wheels live: externally, inner f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
    [pipebot_simplified.step, pipebot_simplified.stl, robot.yaml]
2026-08-12 The ladder de-saturates and ranks compliance; the docs catch up with the measured robot
    Re-ran the #33/#30 four-design step comparison on the adopted platform (radial element
    throughout — the hinge geometrically cannot exist below ~12 segments, and that refusal
    was escaping observe_rover as a raw ValueError; it now returns a typed failure, invariant
    4, test pinned). Result table in the log: rigid cylinder 40 mm (0.67 R), claw family
    60 mm (1.00 R) with the 6-claw INSIDE its measured law — the first rover-level
    compliant-vs-rigid gap that survives the validity rules. Claw counts still tie each
    other, so within-family ranking stays with harshness/washboard. The element is worth
    the whole g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
2026-08-12 The gate's first verdict: cross-platform bit-identity is false, and the lint was never clean CI's first run failed both jobs, and each failure was information. Lint: the "standing 71" had never passe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
    Determinism gate: Linux x86-64 disagreed with the committed arm64 manifests on all 48
    numeric comparisons and none of the structural ones — measured drift ~1e-5 relative on
    positions, up to 3.6% on energy_j, the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
2026-08-12 The scenario suite arrives: S2 slope, S3 gap, S4 rubble, S5 CoT, S6 spin
    Phase 2's first line item, built early on sim/rover.py following S7's pattern — one
    scenario per RoverSpec, any mixture refused by name. S2 tilts GRAVITY rather than the
    floor (an infinite ramp with no entry transient): rigid R 60 holds 10 deg at 0.38 m/s
    and backslides at 40, traction-limited. S3 replaces the floor plane with two slabs and
    a 150 mm trench a plane cannot express: 40 mm crossed, 200 mm swallows a wheel. S4 is
    a procedural 1.2 m rock field where the SEED IS THE TERRAIN — bit-identical per seed,
    rocks buried and height-capped, all by test. S5's cost of transport E/mgd rides on
    every run that moves: 0.0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
2026-08-12 Primitives become the default chassis; the box retires to comparison duty
    The machine simulated is now the machine drawn: chassis_collision defaults to the
    lossless primitive set from pipebot_simplified.stl, with --chassis-collision box
    opting back into the flat-bellied box calibrated to the hand-measured clearance.
    Run identity moved first — S1Config carries chassis_collision in its rung digest,
    because a default flip that changes numbers under an unchanged run_id is the lie
    invariant 5 exists for — and the CI manifests were regenerated under it (3/3).
    The nose-in signature changed and the test records it (v4): at 100 mm on R 85 the
    strike remains but the pitch climbs past 20 deg inste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

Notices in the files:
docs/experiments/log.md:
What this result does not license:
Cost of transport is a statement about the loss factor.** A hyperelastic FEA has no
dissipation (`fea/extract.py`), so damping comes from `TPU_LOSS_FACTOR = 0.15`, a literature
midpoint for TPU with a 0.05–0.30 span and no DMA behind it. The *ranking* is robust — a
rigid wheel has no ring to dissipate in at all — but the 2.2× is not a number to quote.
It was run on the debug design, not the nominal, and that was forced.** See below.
